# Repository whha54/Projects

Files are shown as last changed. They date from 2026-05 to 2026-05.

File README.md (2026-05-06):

# Self-Balancing-Robotic-Desk-Assistant-Scoot-Mk.-1-

A collection of files, code, and images involved in the development of Scoot Mk. 1.

# Overview
Scoot Mk.1 is a small self-balancing robotic desk assistant designed to be a companion for the user as they study or do work. Using buttons on the outside of its frame, the user can also use Scoot as a Pomodoro timer, helping with the user's productivity needs.

# Electronics Description
To develop the electronics for Scoot, I used the CAD tool KiCad to develop the schematic and footprint of the custom PCB. In this PCB, I used an STM32F411 microcontroller due to its high performance compared to the Arduino family of microcontrollers and its 512 KBytes of flash memory, giving me the plenty of space to write code and eliminating the need for external flash memory on the board. Peripherals are a USB-C 2.0 receptacle, ESD protection diode array, motor drivers, battery charger, LED display, accelerometer and gyroscope, an LDO, and 2 N20 motors with magnetic encoders. When making the footprint of the board, I used design techniques such as copper pours and via stitching to reduce the inductance and EMI of the board by reducing the current return loop area. I also made sure to minimize the distance of the USB D- and D+ differential pair and placed decoupling capacitors for every power pin of each IC as close as possible. I also used different trace widths for signal and power pins as thicker traces are needed for the amperage demands for power pins; I used 0.200 mm tracks for signal pins and 0.400 mm tracks for power pins.

# Frame and Software
I am currently in the process of creating the frame of Scoot and the code for Scoot. For the frame, I will use Autodesk Fusion360, and for the code, I plan to use a combination of STM32Cube IDE and Arduino IDE. STM32Cube IDE will allow me to interact directly with the microcontroller to assign pin functions. I will use the Arduino IDE to create the PID algorithm for self-balancing and the Pomodoro timer firmware.

# Future Iterations
- Replace Arduino IDE with C or C++ as programming knowledge expands
- Integrate obstacle-avoidance capabilities

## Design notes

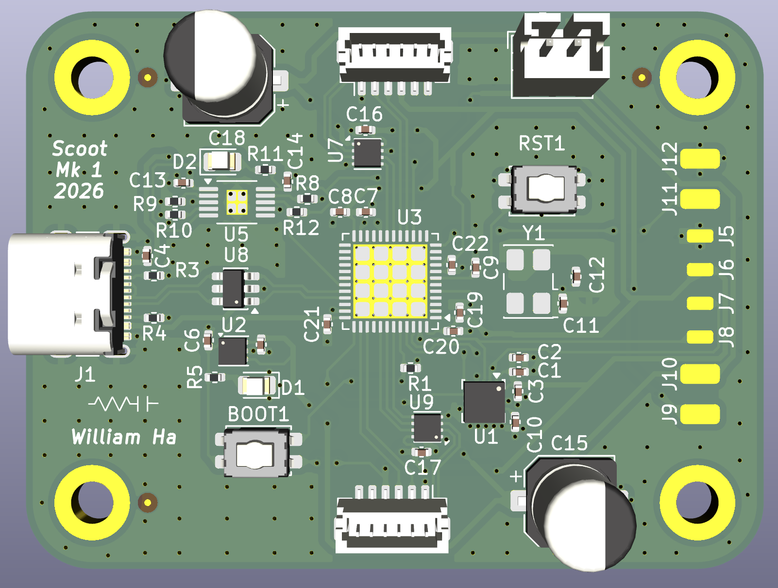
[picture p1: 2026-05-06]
scootmk13D.png

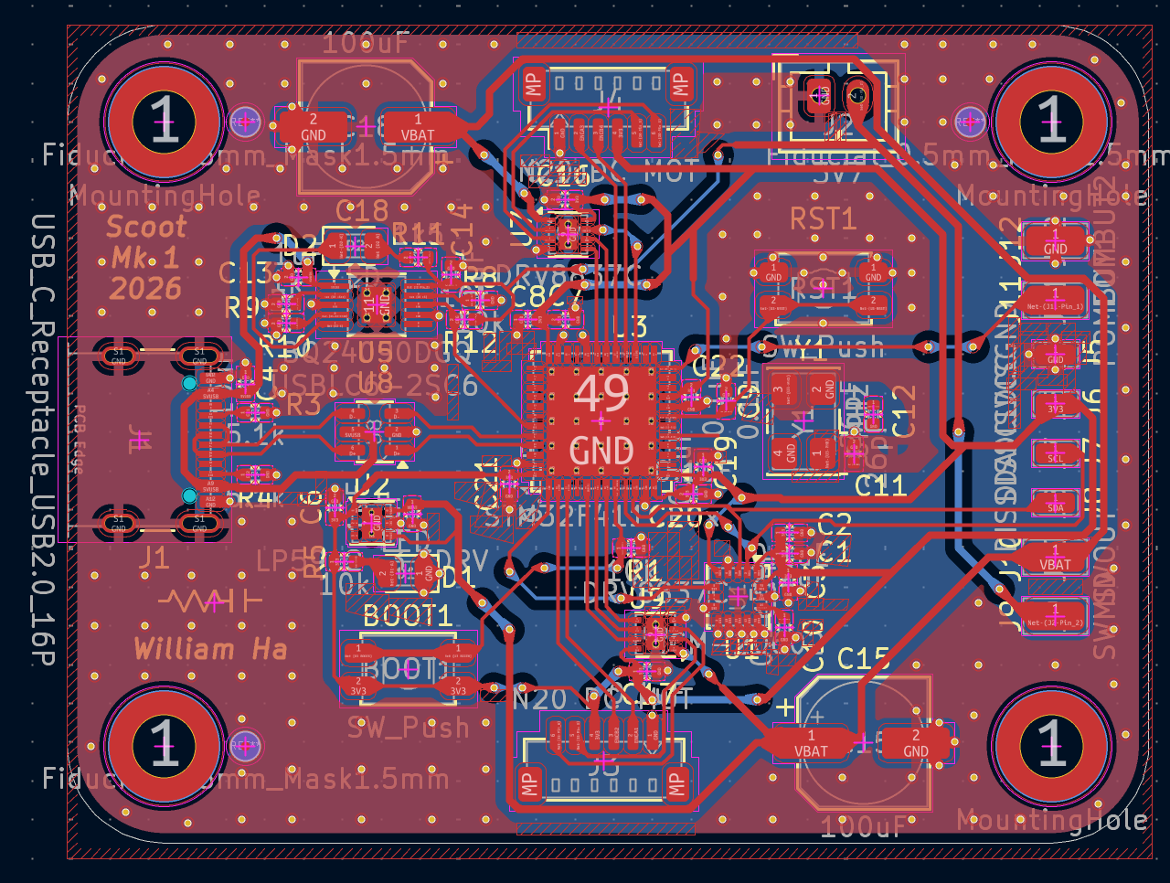
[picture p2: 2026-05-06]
scootmk1fp.png

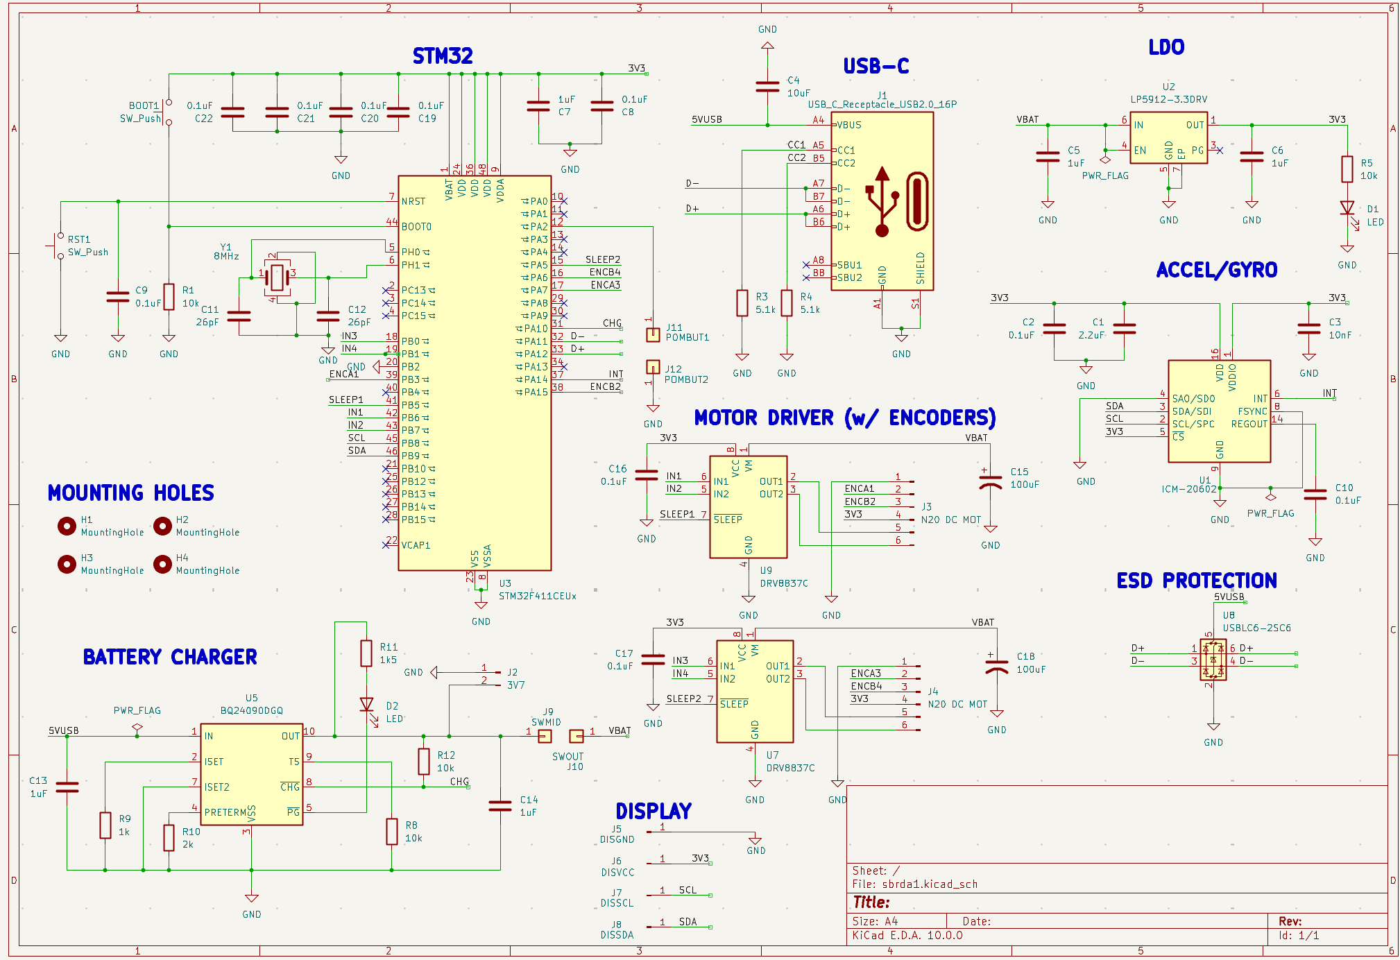
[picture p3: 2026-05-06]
scootmk1sc.png

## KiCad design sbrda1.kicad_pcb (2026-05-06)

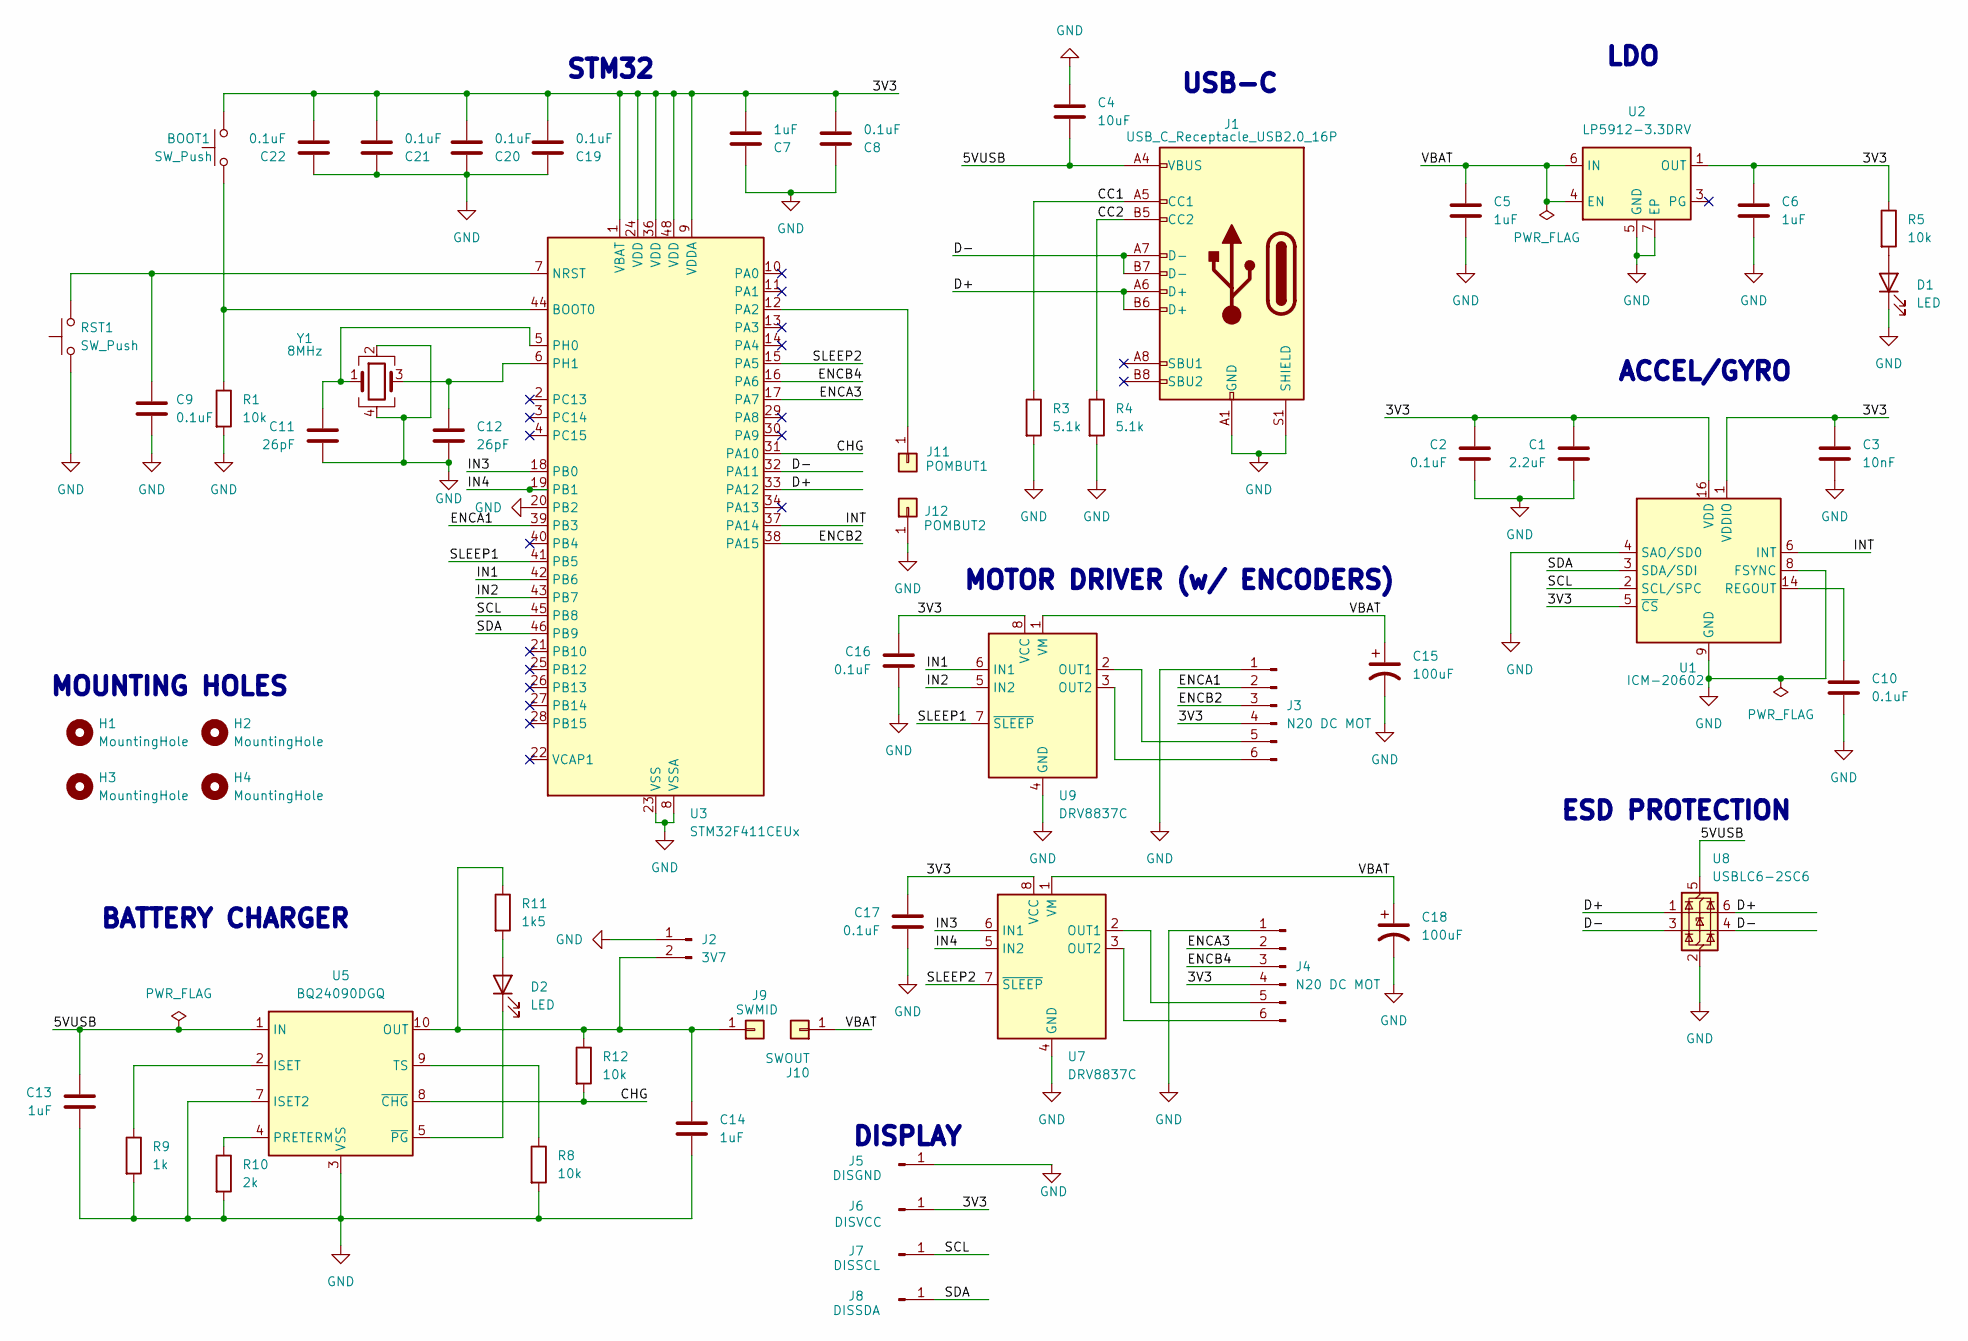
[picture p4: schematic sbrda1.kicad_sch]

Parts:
BOOT1: SW_Push; SW_SPST_EVQP2_ShortPushTravel_H2.1mm
C1: 2.2uF; C_0402_1005Metric
C2, C8, C9, C10, C16, C17, C19, C20, C21, C22: 0.1uF; C_0402_1005Metric
C3: 10nF; C_0402_1005Metric
C4: 10uF; C_0402_1005Metric
C5, C6, C7, C13, C14: 1uF; C_0402_1005Metric
C11, C12: 26pF; C_0402_1005Metric
C15, C18: 100uF; CP_Elec_6.3x7.7
D1, D2: LED; LED_0805_2012Metric
H1, H2, H3, H4: MountingHole; MountingHole_3.2mm_M3_ISO7380_Pad
J1: USB_C_Receptacle_USB2.0_16P; USB_C_Receptacle_GCT_USB4105-xx-A_16P_TopMnt_Horizontal
J2: 3V7; JST_PH_B2B-PH-K_1x02_P2.00mm_Vertical
J3, J4: N20 DC MOT; JST_SH_BM06B-SRSS-TB_1x06-1MP_P1.00mm_Vertical
J5: DISGND; SolderWirePad_1x01_SMD_1x2mm
J6: DISVCC; SolderWirePad_1x01_SMD_1x2mm
J7: DISSCL; SolderWirePad_1x01_SMD_1x2mm
J8: DISSDA; SolderWirePad_1x01_SMD_1x2mm
J9: SWMID; SolderWirePad_1x01_SMD_1.5x3mm
J10: SWOUT; SolderWirePad_1x01_SMD_1.5x3mm
J11: POMBUT1; SolderWirePad_1x01_SMD_1.5x3mm
J12: POMBUT2; SolderWirePad_1x01_SMD_1.5x3mm
R1, R5, R8, R12: 10k; R_0402_1005Metric
R3, R4: 5.1k; R_0402_1005Metric
R9: 1k; R_0402_1005Metric
R10: 2k; R_0402_1005Metric
R11: 1k5; R_0402_1005Metric
RST1: SW_Push; SW_SPST_EVQP2_ShortPushTravel_H2.1mm
U1: ICM-20602; LGA-16_3x3mm_P0.5mm_LayoutBorder3x5y
U2: LP5912-3.3DRV; WSON-6-1EP_2x2mm_P0.65mm_EP1x1.6mm_ThermalVias
U3: STM32F411CEUx; QFN-48-1EP_7x7mm_P0.5mm_EP5.6x5.6mm_ThermalVias
U5: BQ24090DGQ; HVSSOP-10-1EP_3x3mm_P0.5mm_EP1.57x1.88mm_ThermalVias
U7, U9: DRV8837C; WSON-8-1EP_2x2mm_P0.5mm_EP0.9x1.6mm_ThermalVias
U8: USBLC6-2SC6; SOT-23-6
Y1: 8MHz; Crystal_SMD_5032-4Pin_5.0x3.2mm

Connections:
/3V3: BOOT1.2, C1.1, C2.1, C3.1, C6.1, C7.2, C8.2, C16.1, C17.1, C19.2, C20.2, C21.2, C22.2, J3.4, J4.4, J6.1 (Pin_1_1), R5.1, U1.1 (VDDIO), U1.5 (~CS), U1.16 (VDD), U2.1 (OUT), U3.1 (VBAT), U3.9 (VDDA), U3.24 (VDD), U3.36 (VDD), U3.48 (VDD), U7.8 (VCC), U9.8 (VCC)
/5VUSB: C4.2, C13.1, J1.A4 (VBUS), J1.A9 (VBUS), J1.B4 (VBUS), J1.B9 (VBUS), U5.1 (IN), U8.5 (VBUS)
/CC1: J1.A5 (CC1), R3.1
/CC2: J1.B5 (CC2), R4.1
/CHG: R12.2, U3.31 (PA10), U5.8 (~CHG)
/D+: J1.A6 (D+), J1.B6 (D+), U3.33 (PA12), U8.1 (I/O1), U8.6 (I/O1)
/D-: J1.A7 (D-), J1.B7 (D-), U3.32 (PA11), U8.3 (I/O2), U8.4 (I/O2)
/ENCA1: J3.2, U3.39 (PB3)
/ENCA3: J4.2, U3.17 (PA7)
/ENCB2: J3.3, U3.38 (PA15)
/ENCB4: J4.3, U3.16 (PA6)
/IN1: U3.42 (PB6), U9.6 (IN1)
/IN2: U3.43 (PB7), U9.5 (IN2)
/IN3: U3.18 (PB0), U7.6 (IN1)
/IN4: U3.19 (PB1), U7.5 (IN2)
/INT: U1.6 (INT), U3.37 (PA14)
/SCL: J7.1 (Pin_1_1), U1.2 (SCL/SPC), U3.45 (PB8)
/SDA: J8.1 (Pin_1_1), U1.3 (SDA/SDI), U3.46 (PB9)
/SLEEP1: U3.41 (PB5), U9.7 (~SLEEP)
/SLEEP2: U3.15 (PA5), U7.7 (~SLEEP)
/VBAT: C5.1, C15.1, C18.1, J10.1 (Pin_1_1), U2.4 (EN), U2.6 (IN), U7.1 (VM), U9.1 (VM)
GND: C1.2, C2.2, C3.2, C4.1, C5.2, C6.2, C7.1, C8.1, C9.2, C10.2, C11.2, C12.2, C13.2, C14.2, C15.2, C16.2, C17.2, C18.2, C19.1, C20.1, C21.1, C22.1, D1.1 (K), J1.A1 (GND), J1.A12 (GND), J1.B1 (GND), J1.B12 (GND), J1.S1 (SHIELD), J2.1, J3.1, J4.1, J5.1 (Pin_1_1), J12.1 (Pin_1_1), R1.2, R3.2, R4.2, R8.2, R9.2, R10.2, RST1.1, U1.4 (SAO/SD0), U1.8 (FSYNC), U1.9 (GND), U1.10 (GND), U1.11 (GND), U1.12 (GND), U1.13 (GND), U1.15 (GND), U2.5 (GND), U2.7 (EP), U3.8 (VSSA), U3.20 (PB2), U3.23 (VSS), U3.35 (VSS), U3.47 (VSS), U3.49 (VSS), U5.3 (VSS), U5.7 (ISET2), U5.11 (VSS), U7.4 (GND), U7.9 (GND), U8.2 (GND), U9.4 (GND), U9.9 (GND), Y1.2, Y1.4
unnamed: D1.2 (A), R5.2
unnamed: D2.2 (A), R11.2
unnamed: D2.1 (K), U5.5 (~PG)
unnamed: C14.1, J2.2, J9.1 (Pin_1_1), R11.1, R12.1, U5.10 (OUT)
unnamed: J3.5, U9.2 (OUT1)
unnamed: J3.6, U9.3 (OUT2)
unnamed: J4.5, U7.2 (OUT1)
unnamed: J4.6, U7.3 (OUT2)
unnamed: J11.1 (Pin_1_1), U3.12 (PA2)
unnamed: C10.1, U1.14 (REGOUT)
unnamed: BOOT1.1, R1.1, U3.44 (BOOT0)
unnamed: C9.1, RST1.2, U3.7 (NRST)
unnamed: C11.1, U3.5 (PH0), Y1.1
unnamed: C12.1, U3.6 (PH1), Y1.3
unnamed: R9.1, U5.2 (ISET)
unnamed: R10.1, U5.4 (PRETERM)
unnamed: R8.1, U5.9 (TS)

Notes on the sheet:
LDO
STM32
MOUNTING HOLES
MOTOR DRIVER (w/ ENCODERS)
ACCEL/GYRO
ESD PROTECTION
USB-C
BATTERY CHARGER
DISPLAY

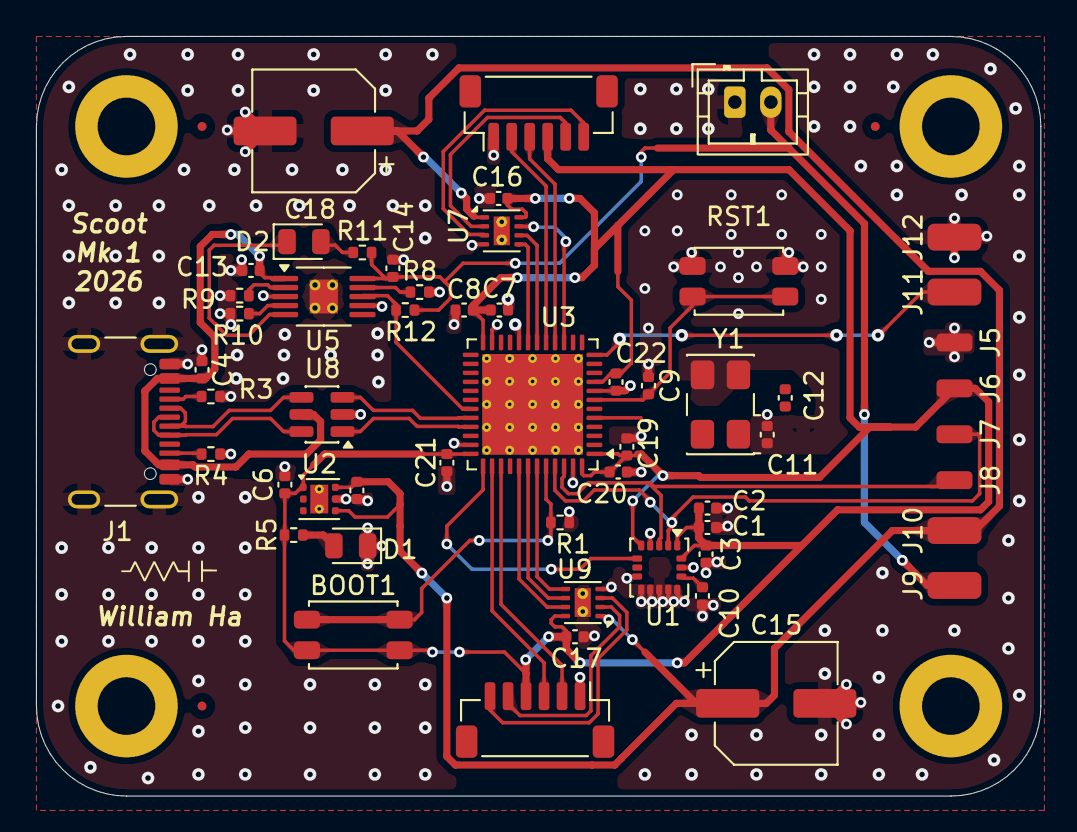
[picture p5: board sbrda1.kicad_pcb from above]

Board: 2 copper layers, 55.8 x 42.2 mm, 59 parts (0 on the bottom side), 39 nets.
